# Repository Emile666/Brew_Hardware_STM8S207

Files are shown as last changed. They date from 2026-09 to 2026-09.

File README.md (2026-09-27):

# Brew Automation Hardware with a STM8S207
This PCB is an evolution of what originally was an Arduino with some added hardware. The current PCB features an STM8S207R8, which comes in a 64 pins LQPF package. It has a maximum of 52 GPIO pins, contains 64K Flash, 1536 bytes EEPROM and 6 KB of RAM. Previous PCB versions were made with Eagle, starting with V4.12, KiCad is used.

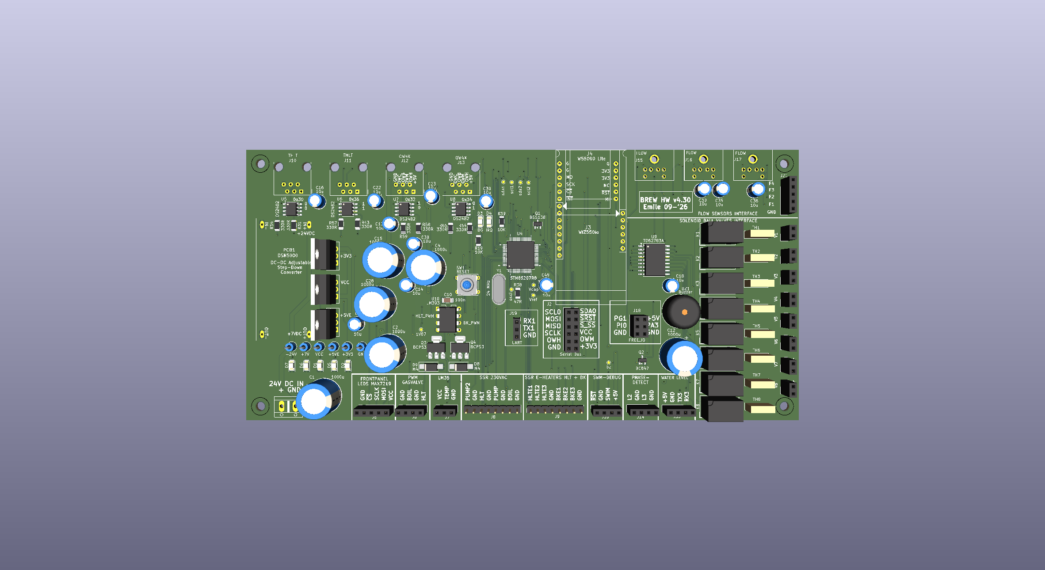
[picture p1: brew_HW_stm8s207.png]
PCB Layout
<br>
*PCB Layout*

# Features
The current PCB and firmware have the following features:
- Reading of **6 x temperature sensors**: two in the HLT (one I2C LM92, one One-Wire DS18B20), one in the MLT (I2C), one in the boil-kettle (One-Wire), one at the output of the counterflow-chiller (One-Wire) and one at the MLT return-manifold (One-Wire).
- Reading of **one hardware temperature** by a LM35 temperature sensor: this is used to protect the Solid State Relays (SSR) from overheating. The LM35 is typically mounted to a heatsink of one of the SSRs that switch a heating-element.
- Reading a maximum of **4 x FS300A flowsensors**: between HLT and MLT, between MLT and boil-kettle, one at the output of the counterflow-chiller and one at the entry of the MLT return-manifold.
- Control of **8 x solenoid ball-valves** at 24 V DC.
- **2 x PWM signals (25 kHz, 28 V DC)** for the modulating gasburners (HLT and boil-kettle burners).
- Control of **4 x SSR outputs at 230 V AC**: the pump, a second pump (for the HLT counterflow-chiller), 230 V enable for the HLT gasburner and 230 V enable for the boil-kettle gasburner.
- Control of **6 x SSR outputs at 230 V AC** for the three phase heating-elements in the HLT and the boil-kettle. With this, heating of the HLT is possible with a gas-burner, with 1, 2 or 3 heating-elements of with any combination of these.
- **Synced SSR outputs** for HLT and boil-kettle, so that you only need **one three-phase connection**. The boil-kettle outputs have priority over the HLT outputs, meaning that if (on any phase of 230 V) both HLT and boil-kettle are heating, only the boil-kettle is activated.
  It is also possible to use just one (or two) of the three-phases, depending on the number of heating-elements inside the HLT and/or boil-kettle. The firmware is capable of addressing one, two or three heating-elements per kettle.
- **Ethernet and USB connection** to PC: USB-connection is used for debugging, main connection between PC-program and the firmware is Ethernet.
- **Frontpanel LEDs (24 in total)** that show the status of all actuators. They are controlled by a MAX7219 LED Display Driver, located on a separate PCB, the frontpanel PCB.

# Schematics (.pdf)
[Brew Hardware schematics](./brew_HW_stm8s207_r430.pdf)<br>
*Brew Hardware Schematics*

# Interactive Bill-of-Materials (BOM)
[Brew Hardware BOM](http://htmlpreview.github.io/?https://github.com/Emile666/Brew_Hardware_STM8S207/blob/main/bom/ibom.html)<br>
*Brew Hardware BOM*

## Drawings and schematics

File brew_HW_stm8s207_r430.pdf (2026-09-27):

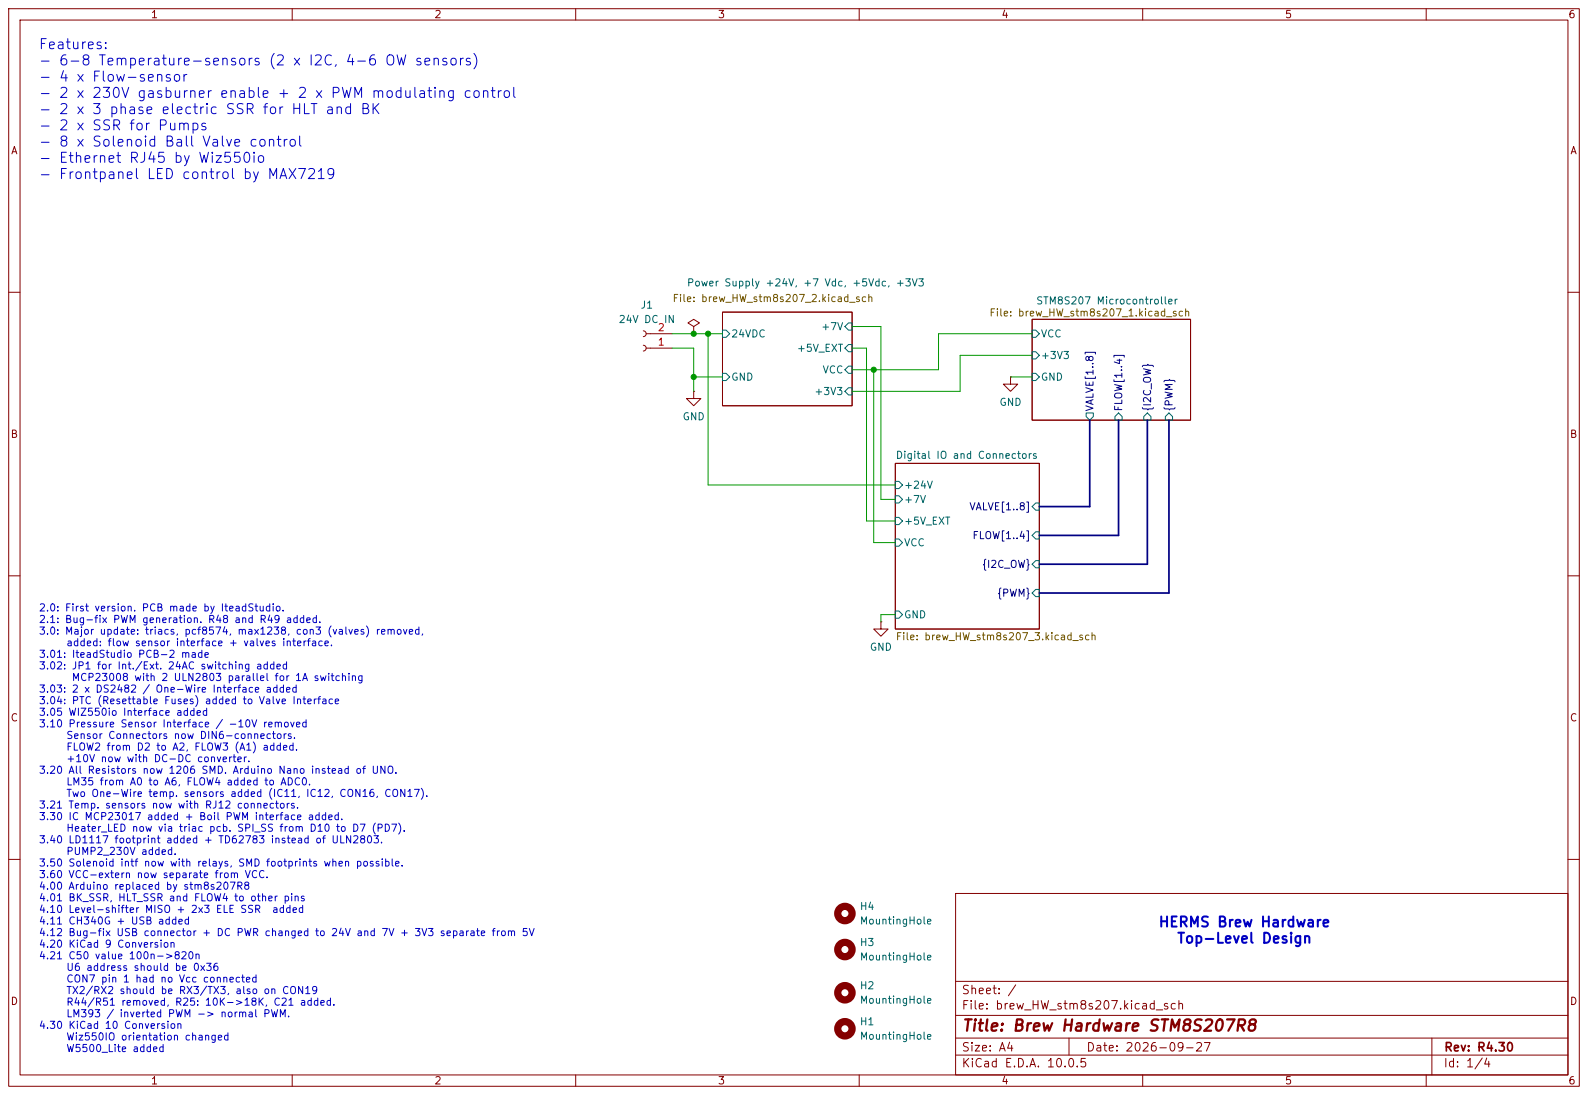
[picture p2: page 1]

Features: - 6-8 Temperature-sensors (2 x I2C, 4-6 OW sensors) - 4 x Flow-sensor - 2 x 230V gasburner enable + 2 x PWM modulating control - 2 x 3 phase electric SSR for HLT and BK - 2 x SSR for Pumps - 8 x Solenoid Ball Valve control - Ethernet RJ45 by Wiz550io - Frontpanel LED control by MAX7219

Digital IO and Connectors File: brew_HW_stm8s207_3.kicad_sch +3V3 GND

2.0: First version. PCB made by IteadStudio. 2.1: Bug-fix PWM generation. R48 and R49 added. 3.0: Major update: triacs, pcf8574, max1238, con3 (valves) removed, added: flow sensor interface + valves interface. 3.01: IteadStudio PCB-2 made 3.02: JP1 for Int./Ext. 24AC switching added MCP23008 with 2 ULN2803 parallel for 1A switching 3.03: 2 x DS2482 / One-Wire Interface added 3.04: PTC (Resettable Fuses) added to Valve Interface 3.05 WIZ550io Interface added 3.10 Pressure Sensor Interface / -10V removed Sensor Connectors now DIN6-connectors. FLOW2 from D2 to A2, FLOW3 (A1) added. +10V now with DC-DC converter. 3.20 All Resistors now 1206 SMD. Arduino Nano instead of UNO. LM35 from A0 to A6, FLOW4 added to ADC0. Two One-Wire temp. sensors added (IC11, IC12, CON16, CON17). 3.21 Temp. sensors now with RJ12 connectors. 3.30 IC MCP23017 added + Boil PWM interface added. Heater_LED now via triac pcb. SPI_SS from D10 to D7 (PD7). 3.40 LD1117 footprint added + TD62783 instead of ULN2803. PUMP2_230V added. 3.50 Solenoid intf now with relays, SMD footprints when possible. 3.60 VCC-extern now separate from VCC. 4.00 Arduino replaced by stm8s207R8

4.01 BK_SSR, HLT_SSR and FLOW4 to other pins 4.10 Level-shifter MISO + 2x3 ELE SSR added 4.11 CH340G + USB added 4.12 Bug-fix USB connector + DC PWR changed to 24V and 7V + 3V3 separate from 5V 4.20 KiCad 9 Conversion 4.21 C50 value 100n->820n U6 address should be 0x36 CON7 pin 1 had no Vcc connected

TX2/RX2 should be RX3/TX3, also on CON19 R44/R51 removed, R25: 10K->18K, C21 added. LM393 / inverted PWM -> normal PWM. 4.30 KiCad 10 Conversion Wiz550IO orientation changed W5500_Lite added

Size: A4 | Rev: R4.30
KiCad E.D.A. 10.0.5 | Id: 1/4

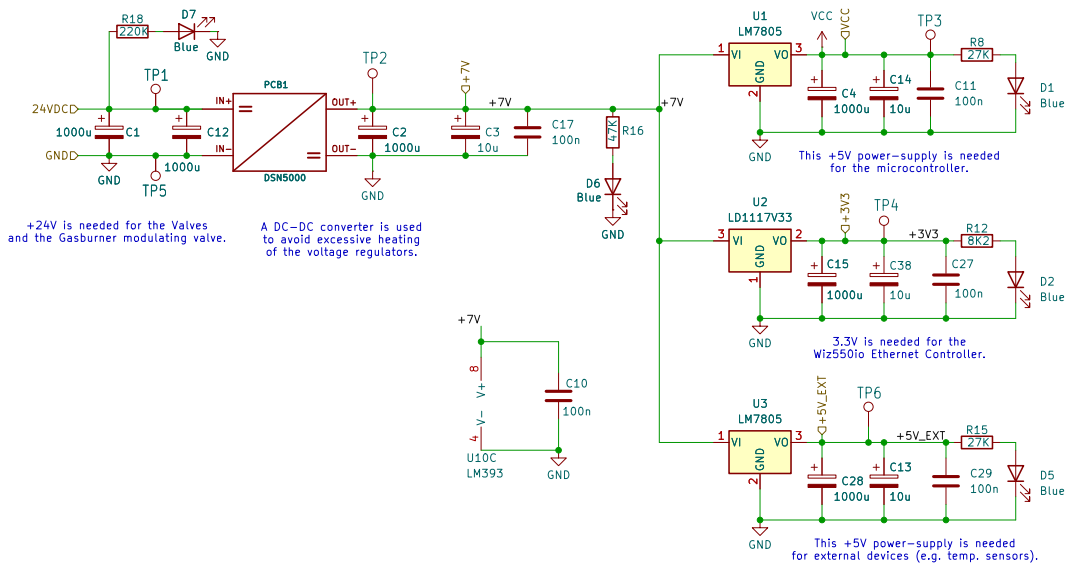
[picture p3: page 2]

for the microcontroller. A DC-DC converter is used

for external devices (e.g. temp. sensors). This +5V power-supply is needed

to avoid excessive heating
of the voltage regulators.

Sheet: /Power Supply +24V, +7 Vdc, +5Vdc, +3V3/
File: brew_HW_stm8s207_2.kicad_sch
Title: Brew Hardware STM8S207R8

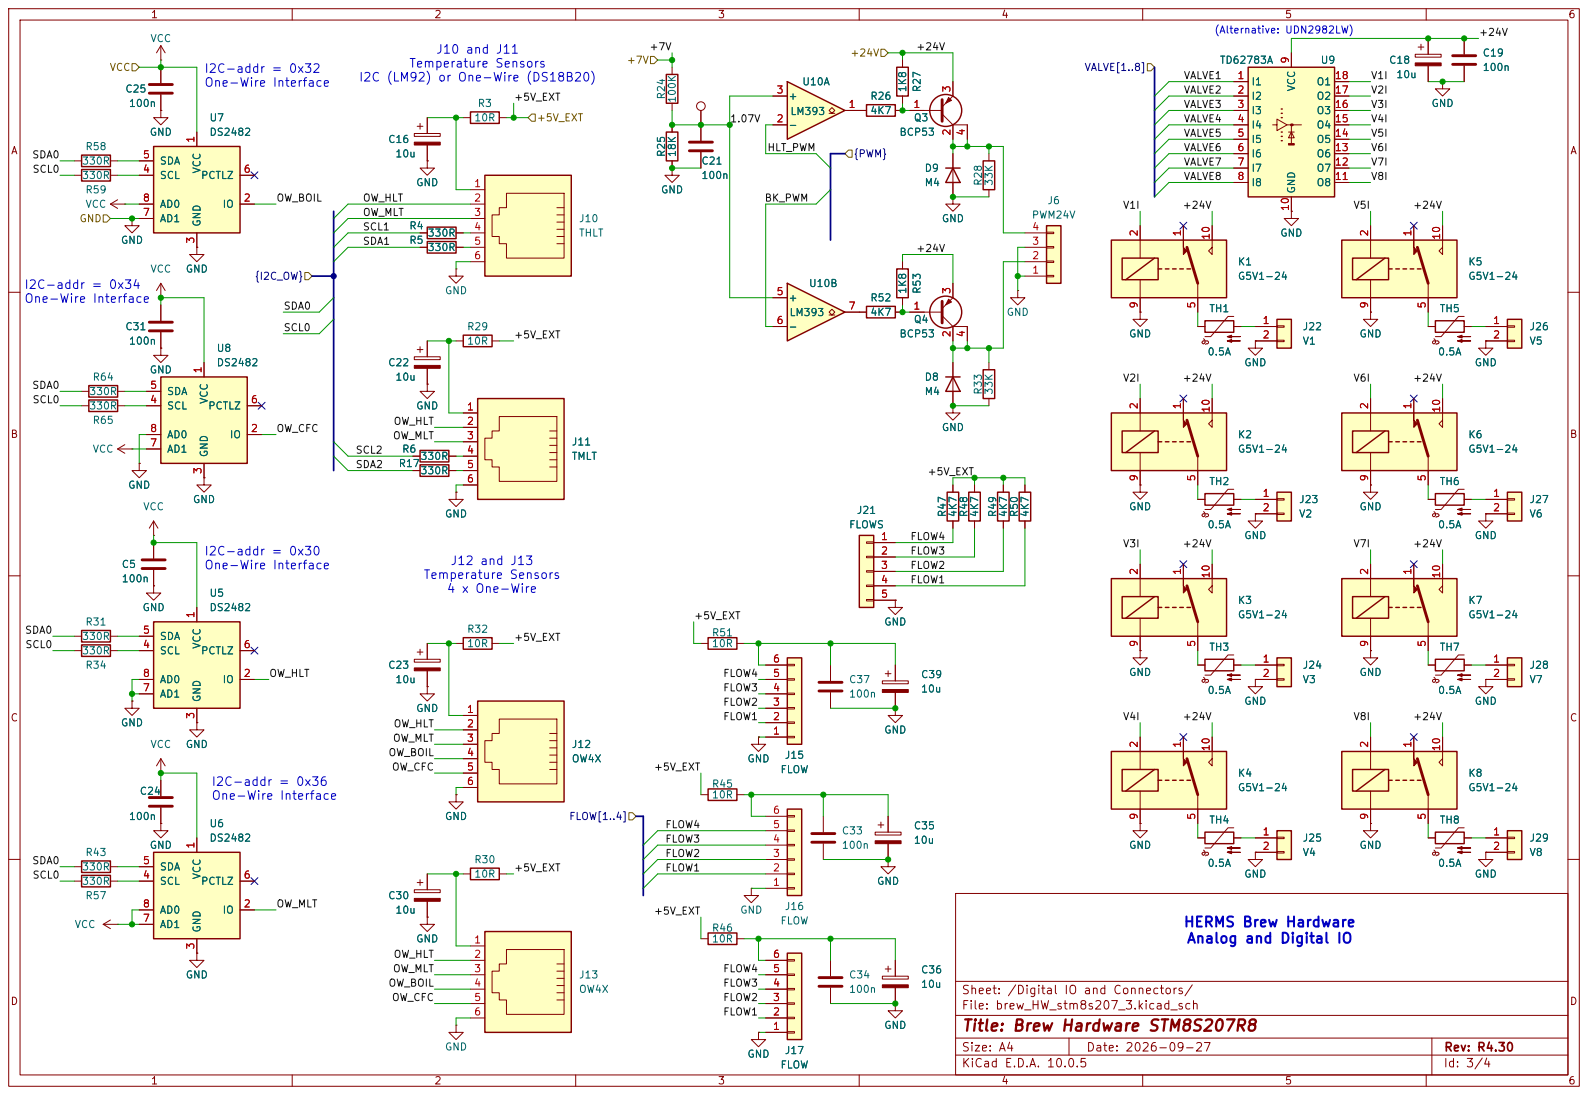
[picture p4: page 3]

330R | SCL 4

HERMS Brew Hardware
Analog and Digital IO

Sheet: /Digital IO and Connectors/
File: brew_HW_stm8s207_3.kicad_sch
Title: Brew Hardware STM8S207R8

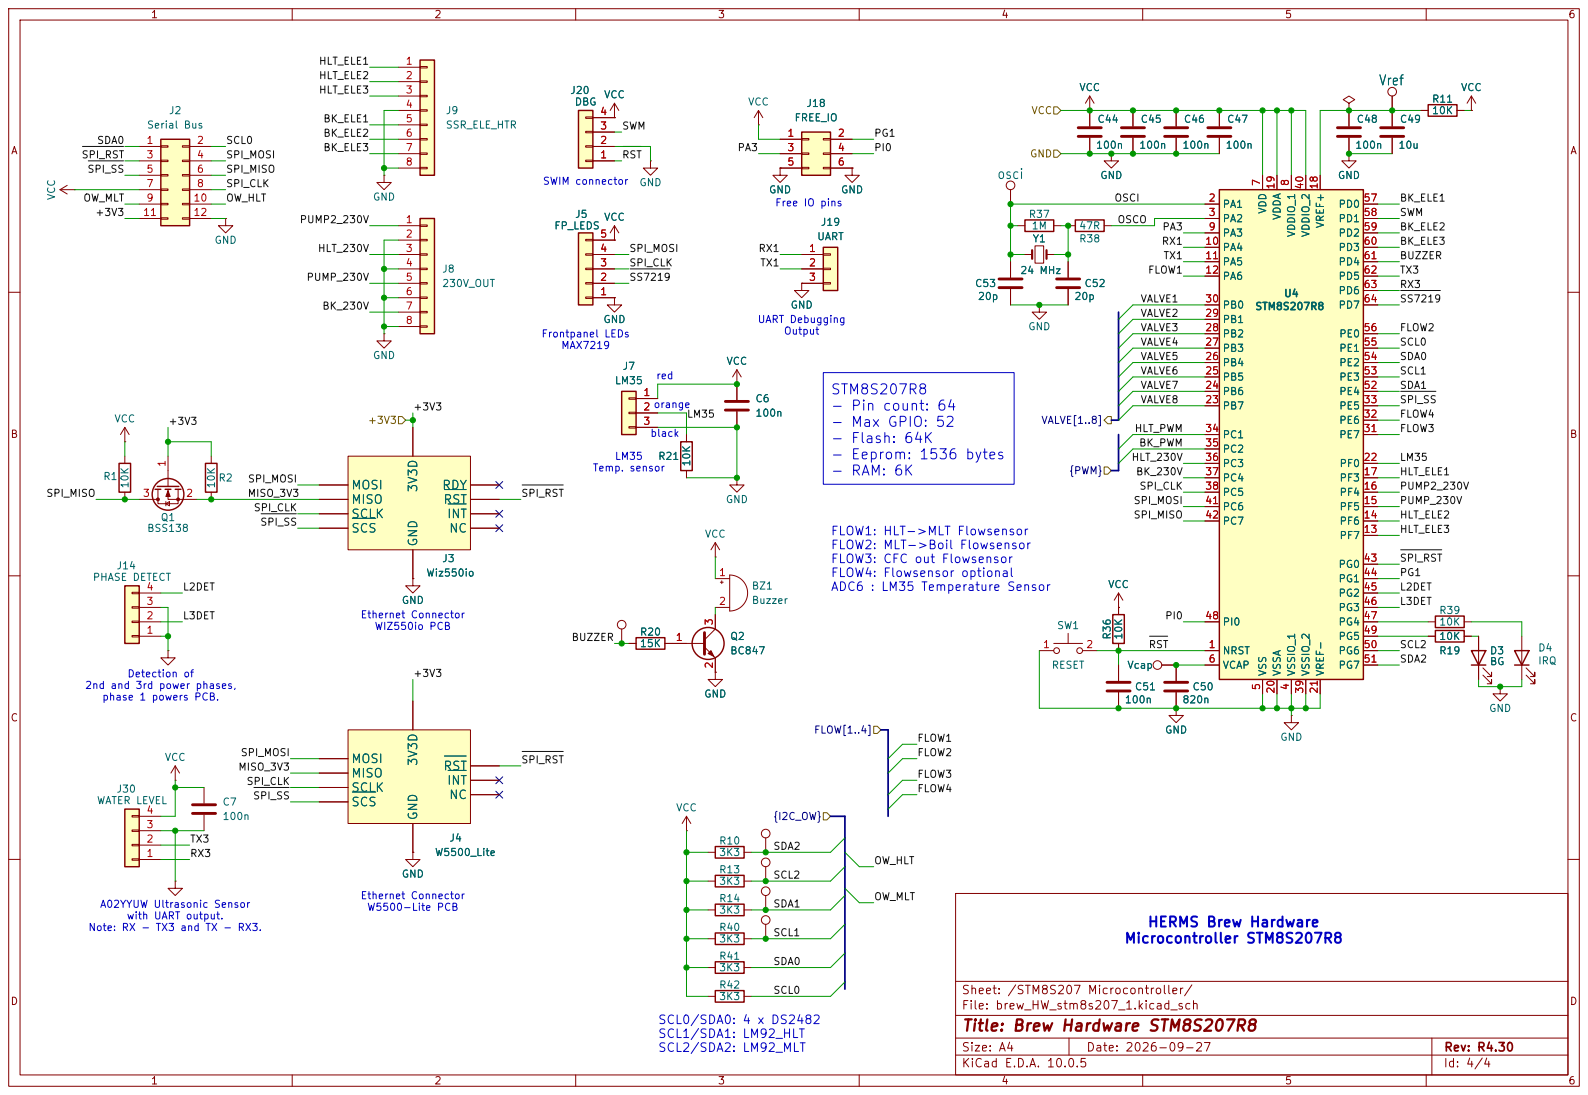
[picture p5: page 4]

8 PA3 9 PA4 10 PA5 11 PA6 12 PF7 13 PF6 14 PF5 15 PF4 16 PF3 17 VREF+ 18 VDDA 19 VSSA 20 VREF- 21 PF0 22 PB7 23 PB6 24 PB5 25 PB4 26 PB3 27 PB2 28 PB1 29 PB0 30 PE7 31 PE6 32 PE5 33 PC1 34 PC2 35 PC3 36 PC4 37 PC5 38 VSSIO_2 39 VDDIO_2 40 PC6 41 PC7 42 PG0 43 PG1 44 PG2 45 PG3 46 PG4 47 PI0 48 PG5 49 PG6 50 PG7 51 PE4 52 PE3 53 PE2 54 PE1 55 PE0 56 PD0 57 PD1 58 PD2 59 PD3 60 PD4 61 PD5 62 PD6 63 PD7 64 U4

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

Output Detection of 2nd and 3rd power phases,

STM8S207R8 - Pin count: 64 - Max GPIO: 52 - Flash: 64K - Eeprom: 1536 bytes - RAM: 6K

orange black Ethernet Connector WIZ550io PCB

phase 1 powers PCB. A02YYUW Ultrasonic Sensor with UART output. Note: RX - TX3 and TX - RX3.

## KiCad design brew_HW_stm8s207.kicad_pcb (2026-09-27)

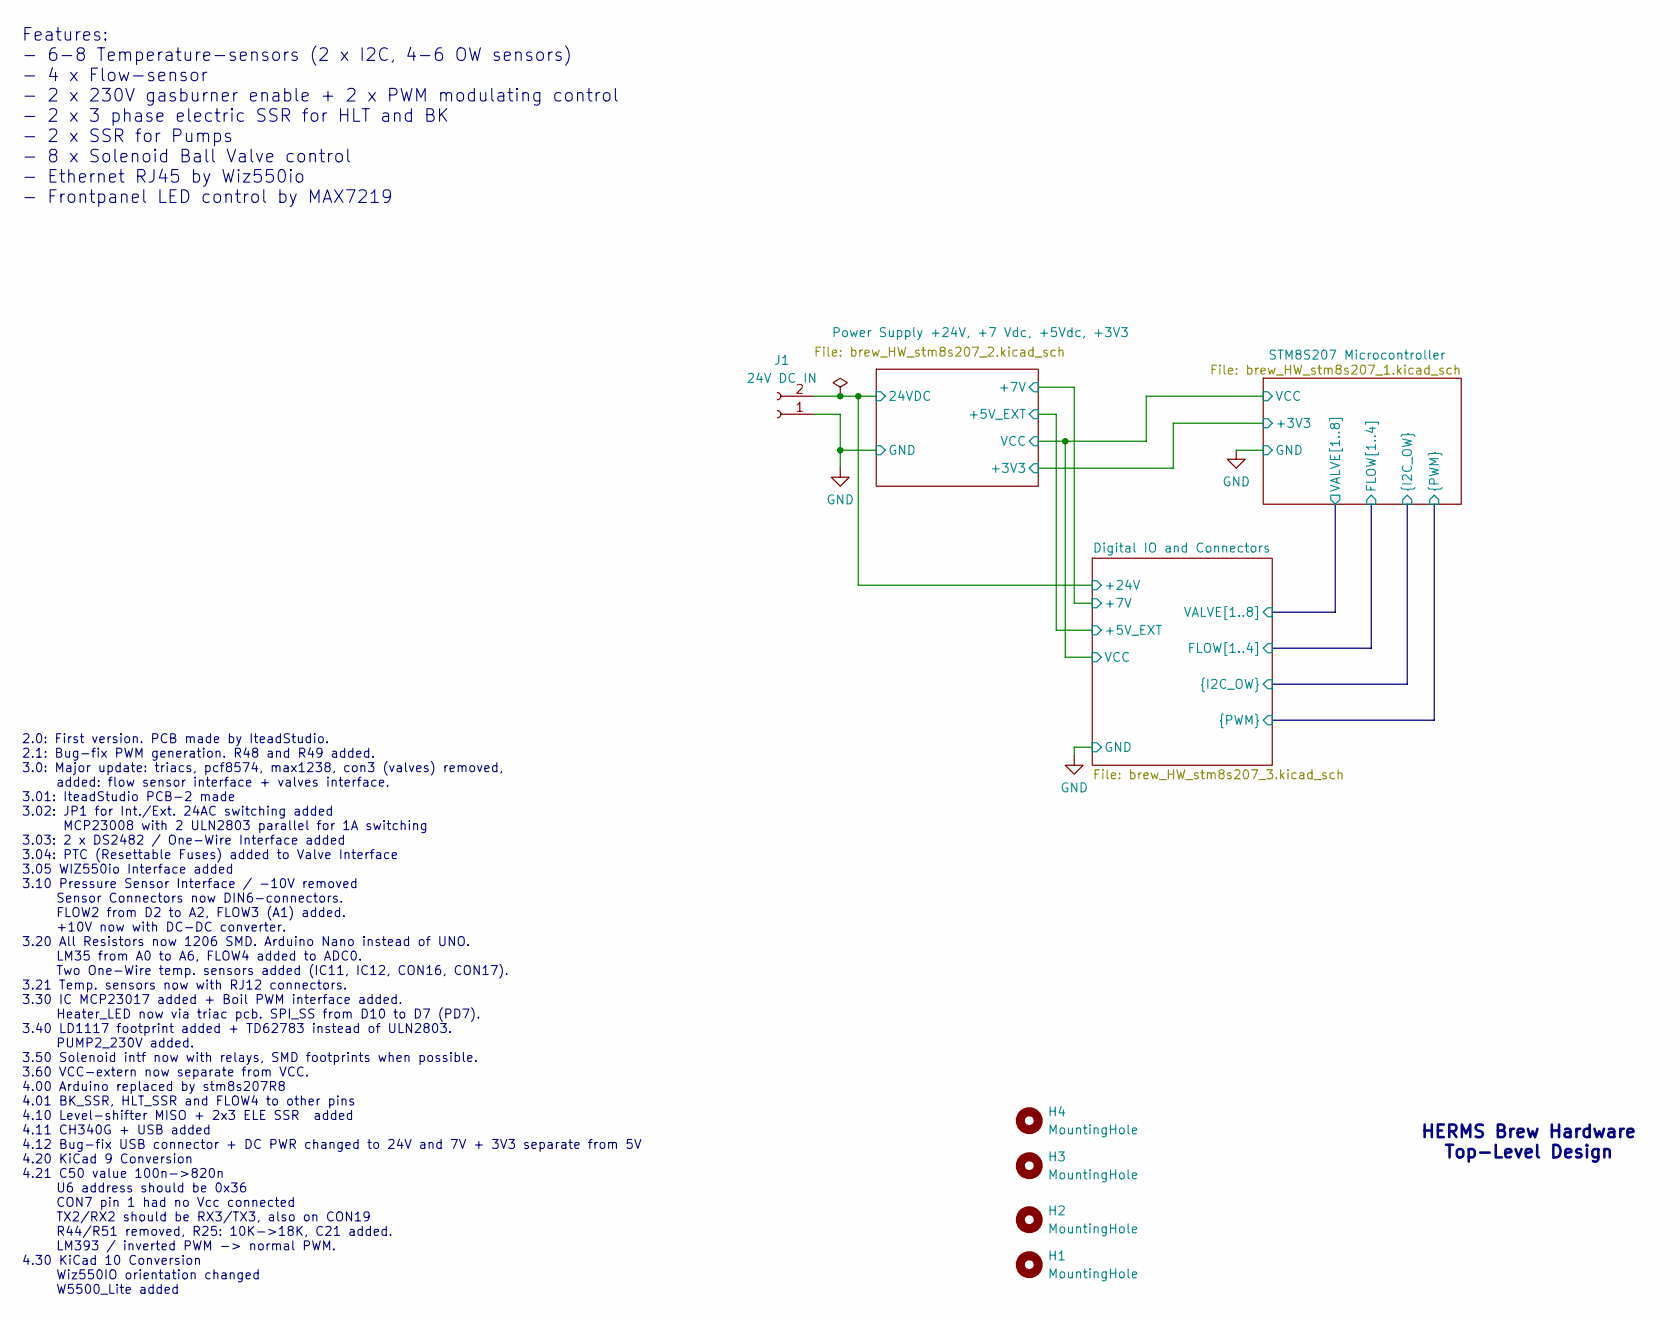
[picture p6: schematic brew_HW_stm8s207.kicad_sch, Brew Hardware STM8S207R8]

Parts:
H1, H2, H3, H4: MountingHole; MountingHole_3.2mm_M3
J1: 24V DC IN; AK500_2

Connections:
/Digital IO and Connectors/+24V: J1.2; also elsewhere on the board
GND: J1.1; also elsewhere on the board

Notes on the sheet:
Features: - 6-8 Temperature-sensors (2 x I2C, 4-6 OW sensors) - 4 x Flow-sensor - 2 x 230V gasburner enable + 2 x PWM modulating control - 2 x 3 phase electric SSR for HLT and BK - 2 x SSR for Pumps - 8 x Solenoid Ball Valve control - Ethernet RJ45 by Wiz550io - Frontpanel LED control by MAX7219
2.0: First version. PCB made by IteadStudio. 2.1: Bug-fix PWM generation. R48 and R49 added. 3.0: Major update: triacs, pcf8574, max1238, con3 (valves) removed, added: flow sensor interface + valves interface. 3.01: IteadStudio PCB-2 made 3.02: JP1 for Int./Ext. 24AC switching added MCP23008 with 2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
HERMS Brew Hardware Top-Level Design

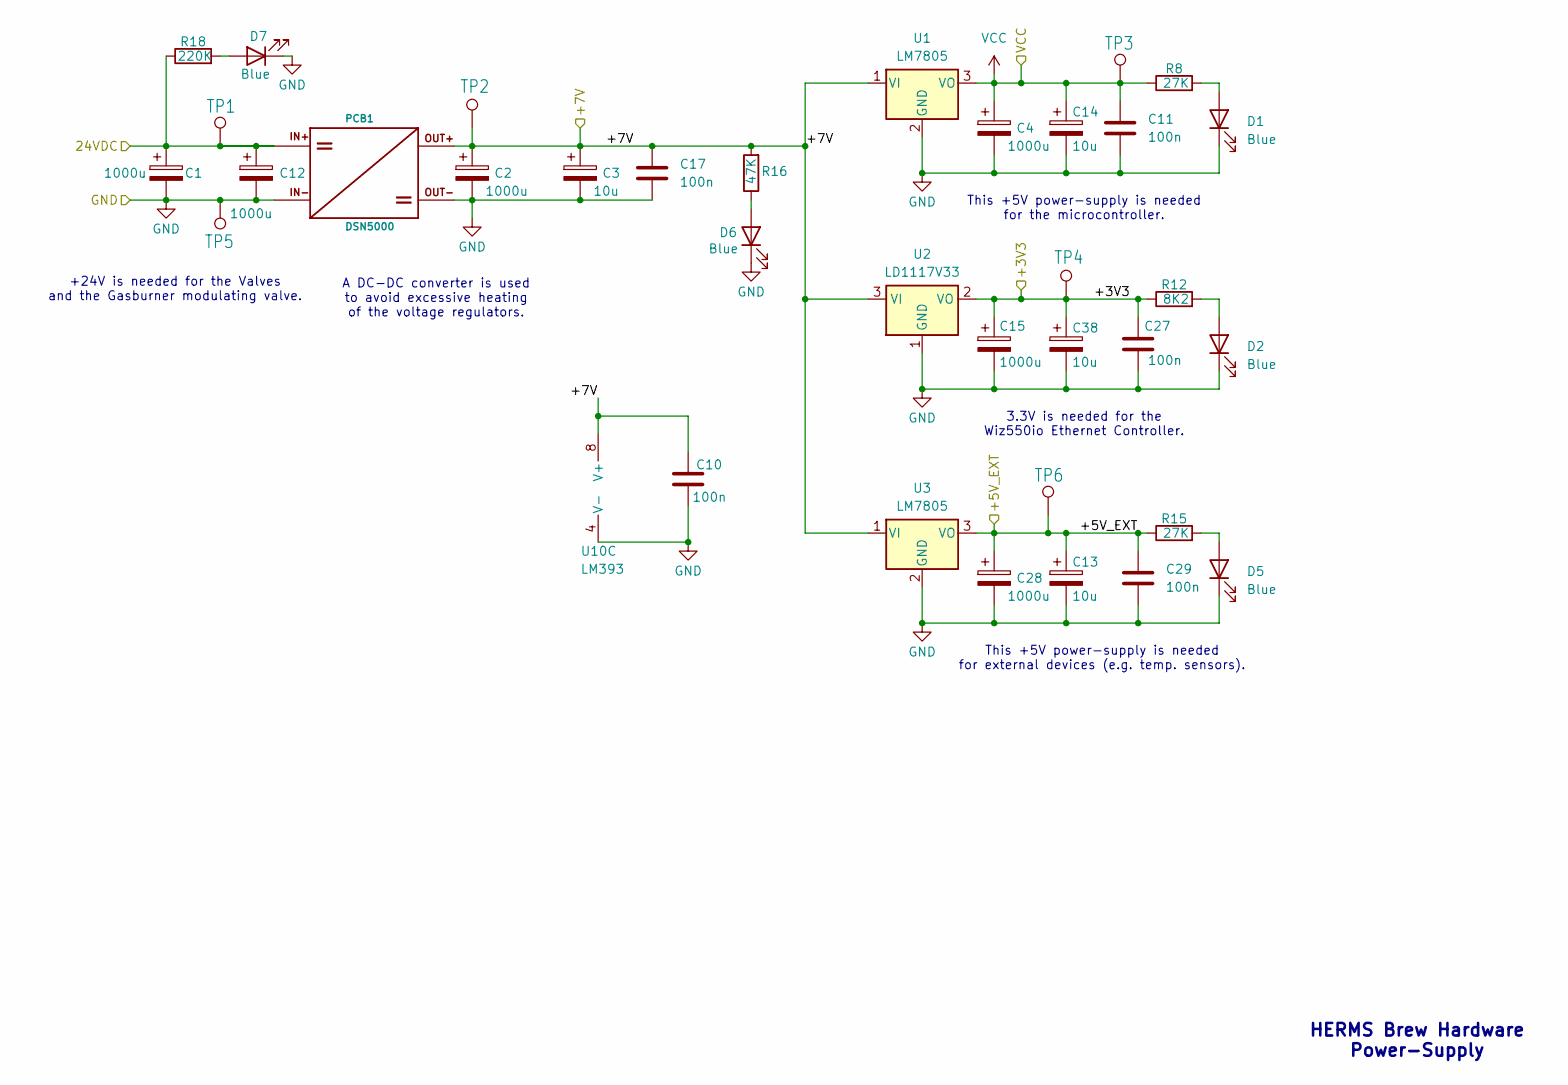
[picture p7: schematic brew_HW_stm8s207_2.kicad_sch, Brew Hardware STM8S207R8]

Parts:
C1, C2, C4, C12, C15, C28: 1000u; CP_Radial_D12.5mm_P5.00mm
C3, C13, C14, C38: 10u; CP_Radial_D5.0mm_P2.00mm
C10, C11, C17, C27, C29: 100n; C_1206_3216Metric
D1, D2, D5, D6, D7: Blue; LED_1206_3216Metric
PCB1: DSN5000; DSN5000_DCDC_CONVERTER
R8, R15: 27K; R_1206_3216Metric
R12: 8K2; R_1206_3216Metric
R16: 47K; R_1206_3216Metric
R18: 220K; R_1206_3216Metric
TP1: +24V; TestPoint_Loop_D2.54mm_Drill1.5mm_Beaded
TP2: +7V; TestPoint_Loop_D2.54mm_Drill1.5mm_Beaded
TP3: VCC; TestPoint_Loop_D2.54mm_Drill1.5mm_Beaded
TP4: +3V3; TestPoint_Loop_D2.54mm_Drill1.5mm_Beaded
TP5: GND; TestPoint_Loop_D2.54mm_Drill1.5mm_Beaded
TP6: +5VE; TestPoint_Loop_D2.54mm_Drill1.5mm_Beaded
U1, U3: LM7805; TO-220-3_Vertical
U2: LD1117V33; TO-220-3_Vertical
U10: LM393; DIP-8_W7.62mm

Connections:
/Digital IO and Connectors/+5V_EXT: C13.1, C28.1, C29.1, R15.1, TP6.1 (1_1), U3.3 (VO); also elsewhere on the board
/Digital IO and Connectors/+7V: C2.1, C3.1, C10.1, C17.1, PCB1.P$3, R16.2, TP2.1 (1_1), U1.1 (VI), U2.3 (VI), U3.1 (VI), U10.8 (V+); also elsewhere on the board
/Digital IO and Connectors/+24V: C1.1, C12.1, PCB1.PX$1 (IN+), R18.1, TP1.1 (1_1); also elsewhere on the board
/Power Supply +24V, +7 Vdc, +5Vdc, +3V3/+3V3: C15.1, C27.1, C38.1, R12.1, TP4.1 (1_1), U2.2 (VO); also elsewhere on the board
GND: C1.2, C2.2, C3.2, C4.2, C10.2, C11.2, C12.2, C13.2, C14.2, C15.2, C17.2, C27.2, C28.2, C29.2, C38.2, D1.1 (K), D2.1 (K), D5.1 (K), D6.1 (K), D7.1 (K), PCB1.P$2, PCB1.P$4, TP5.1 (1_1), U1.2 (GND), U2.1 (GND), U3.2 (GND), U10.4 (V-); also elsewhere on the board
unnamed: D1.2 (A), R8.2
unnamed: D2.2 (A), R12.2
unnamed: D5.2 (A), R15.2
unnamed: D6.2 (A), R16.1
unnamed: D7.2 (A), R18.2
VCC: C4.1, C11.1, C14.1, R8.1, TP3.1 (1_1), U1.3 (VO); also elsewhere on the board

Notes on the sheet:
This +5V power-supply is needed for external devices (e.g. temp. sensors).
+24V is needed for the Valves and the Gasburner modulating valve.
HERMS Brew Hardware Power-Supply
This +5V power-supply is needed for the microcontroller.
A DC-DC converter is used to avoid excessive heating of the voltage regulators.
3.3V is needed for the Wiz550io Ethernet Controller.

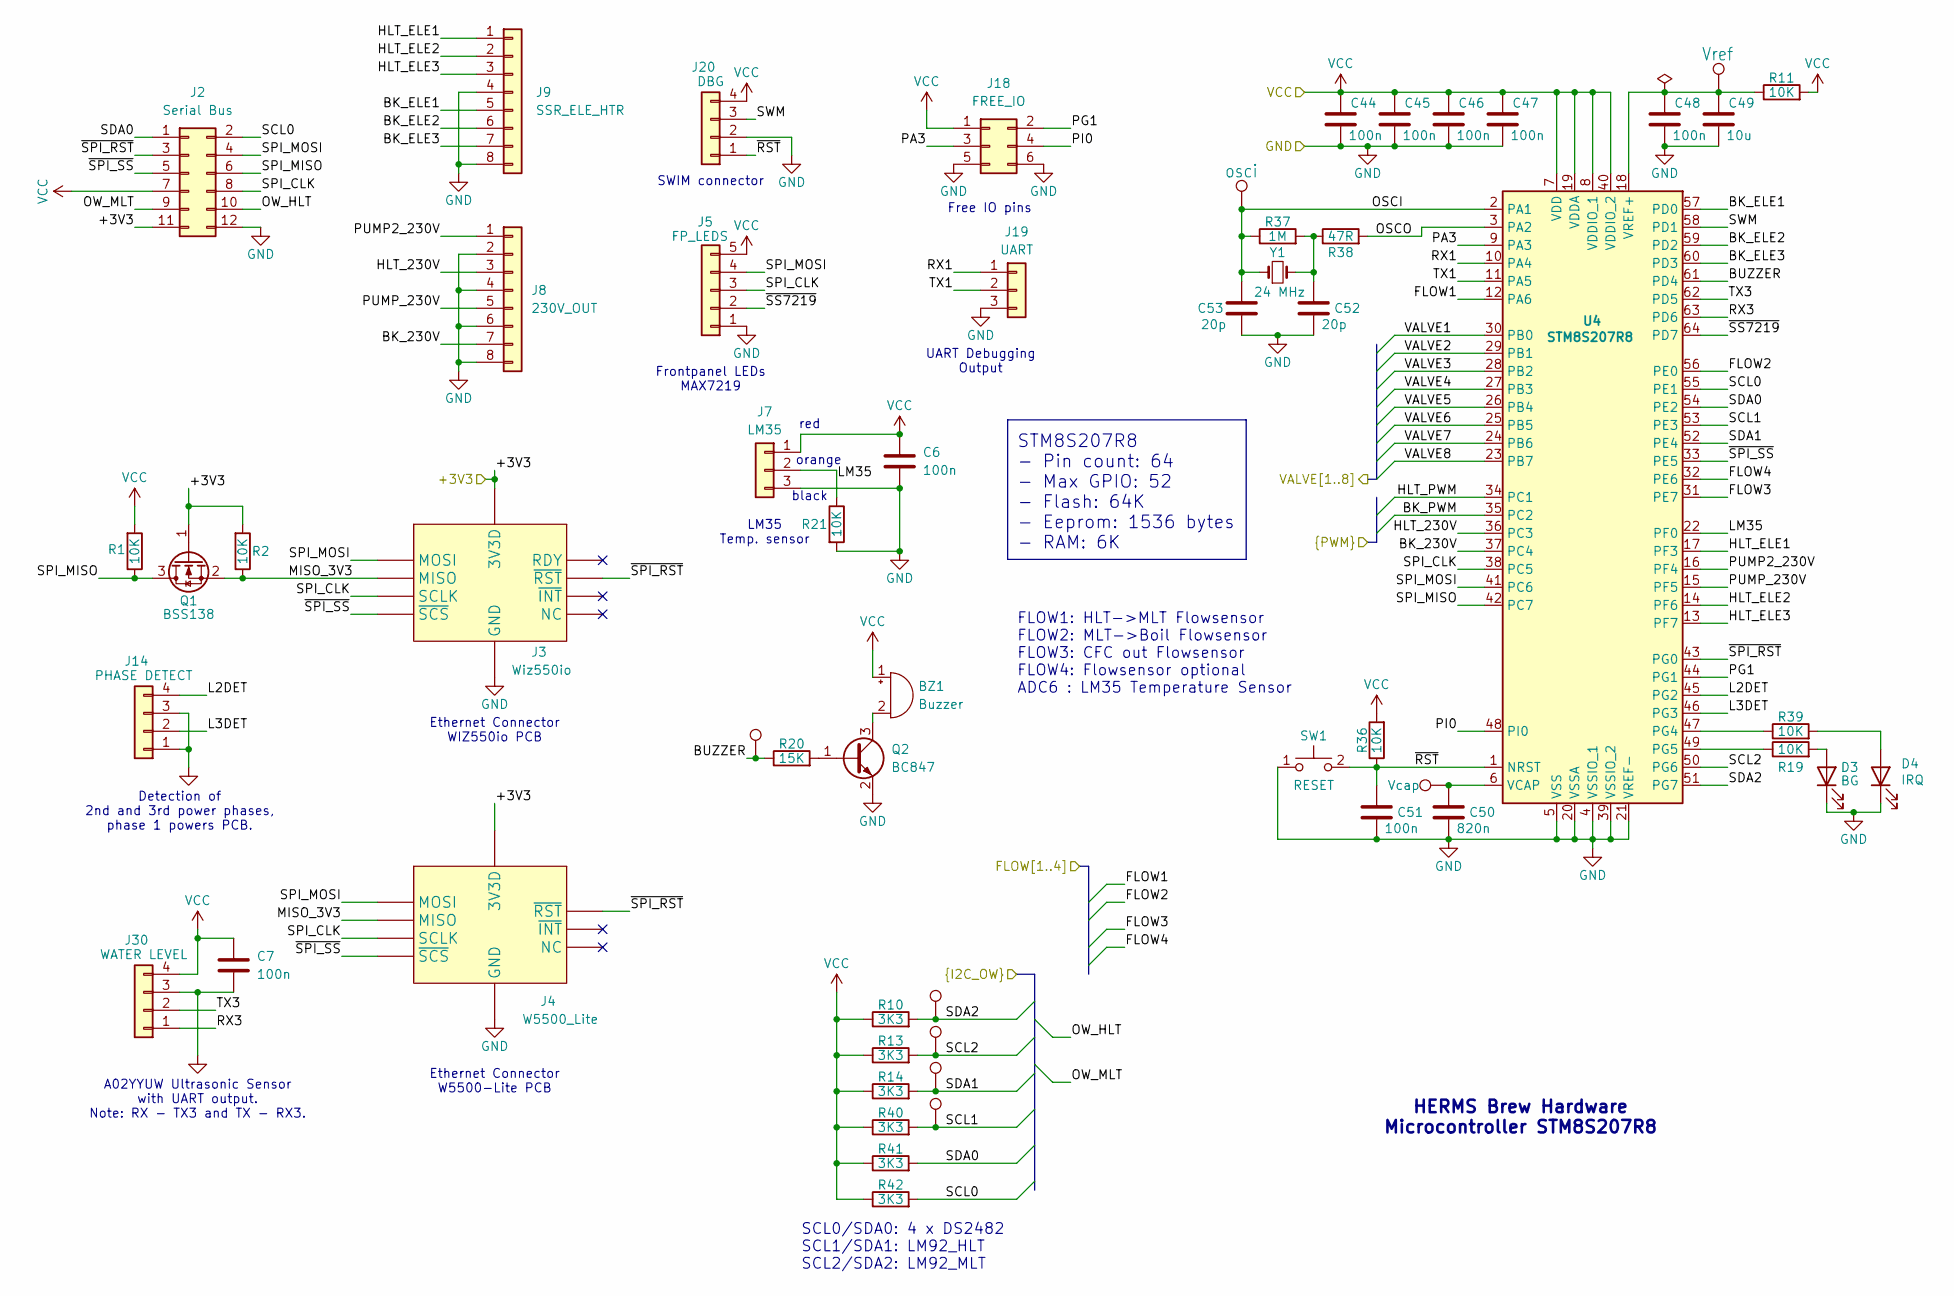
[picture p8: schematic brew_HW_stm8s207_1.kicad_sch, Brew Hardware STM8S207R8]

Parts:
BZ1: Buzzer; Buzzer_12x9.5RM7.6
C6, C7, C44, C45, C46, C47, C48, C51: 100n; C_1206_3216Metric
C49: 10u; CP_Radial_D5.0mm_P2.00mm
C50: 820n; C_1206_3216Metric
C52, C53: 20p; C_1206_3216Metric
D3: BG; LED_1206_3216Metric
D4: IRQ; LED_1206_3216Metric
J2: Serial Bus; PinSocket_2x06_P2.54mm_Vertical
J3: Wiz550io; WIZ550IO
J4: W5500_Lite; W55000_Lite
J5: FP_LEDS; PinSocket_1x05_P2.54mm_Vertical
J7: LM35; PinSocket_1x03_P2.54mm_Vertical
J8: 230V_OUT; PinHeader_1x08_P2.54mm_Vertical
J9: SSR_ELE_HTR; PinHeader_1x08_P2.54mm_Vertical
J14: PHASE DETECT; PinSocket_1x04_P2.54mm_Vertical
J18: FREE_IO; PinSocket_2x03_P2.54mm_Vertical
J19: UART; PinSocket_1x03_P2.54mm_Vertical
J20: DBG; PinSocket_1x04_P2.54mm_Vertical
J30: WATER LEVEL; PinSocket_1x04_P2.54mm_Vertical
Q1: BSS138; SOT-23
Q2: BC847; SOT-23
R1, R2, R11, R19, R21, R36, R39: 10K; R_1206_3216Metric
R10, R13, R14, R40, R41, R42: 3K3; R_1206_3216Metric
R20: 15K; R_1206_3216Metric
R37: 1M; R_1206_3216Metric
R38: 47R; R_1206_3216Metric
SW1: RESET; SW_Tactile_Straight_KSA0Axx1LFTR
TP7: Vref; TestPoint_Pad_D1.0mm
TP8: Vcap; TestPoint_Pad_D1.0mm
TP9: sda2; TestPoint_Pad_D1.0mm
TP10: scl2; TestPoint_Pad_D1.0mm
TP11: sda1; TestPoint_Pad_D1.0mm
TP12: scl1; TestPoint_Pad_D1.0mm
TP13: bz; TestPoint_Pad_D1.0mm
TP14: osci; TestPoint_Pad_D1.0mm
U4: STM8S207R8; LQFP-64_10x10mm_P0.5mm
Y1: 24 MHz; Crystal_HC49-4H_Vertical

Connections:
/Digital IO and Connectors/BK_PWM: U4.35 (PC2); also elsewhere on the board
/Digital IO and Connectors/FLOW1: U4.12 (PA6); also elsewhere on the board
/Digital IO and Connectors/FLOW2: U4.56 (PE0); also elsewhere on the board
/Digital IO and Connectors/FLOW3: U4.31 (PE7); also elsewhere on the board
/Digital IO and Connectors/FLOW4: U4.32 (PE6); also elsewhere on the board
/Digital IO and Connectors/HLT_PWM: U4.34 (PC1); also elsewhere on the board
/Digital IO and Connectors/OW_HLT: J2.10; also elsewhere on the board
/Digital IO and Connectors/OW_MLT: J2.9; also elsewhere on the board
/Digital IO and Connectors/SCL0: J2.2, R42.2, U4.55 (PE1); also elsewhere on the board
/Digital IO and Connectors/SCL1: R40.2, TP12.1 (1_1), U4.53 (PE3); also elsewhere on the board
/Digital IO and Connectors/SCL2: R13.2, TP10.1 (1_1), U4.50 (PG6); also elsewhere on the board
/Digital IO and Connectors/SDA0: J2.1, R41.2, U4.54 (PE2); also elsewhere on the board
/Digital IO and Connectors/SDA1: R14.2, TP11.1 (1_1), U4.52 (PE4); also elsewhere on the board
/Digital IO and Connectors/SDA2: R10.2, TP9.1 (1_1), U4.51 (PG7); also elsewhere on the board
/Digital IO and Connectors/VALVE1: U4.30 (PB0); also elsewhere on the board
/Digital IO and Connectors/VALVE2: U4.29 (PB1); also elsewhere on the board
/Digital IO and Connectors/VALVE3: U4.28 (PB2); also elsewhere on the board
/Digital IO and Connectors/VALVE4: U4.27 (PB3); also elsewhere on the board
/Digital IO and Connectors/VALVE5: U4.26 (PB4); also elsewhere on the board
/Digital IO and Connectors/VALVE6: U4.25 (PB5); also elsewhere on the board
/Digital IO and Connectors/VALVE7: U4.24 (PB6); also elsewhere on the board
/Digital IO and Connectors/VALVE8: U4.23 (PB7); also elsewhere on the board
/Power Supply +24V, +7 Vdc, +5Vdc, +3V3/+3V3: J2.11, J3.6 (3V3D), J4.6 (3V3D), Q1.1 (G), R2.2; also elsewhere on the board
/STM8S207 Microcontroller/BK_230V: J8.7, U4.37 (PC4)
/STM8S207 Microcontroller/BK_ELE1: J9.5, U4.57 (PD0)
/STM8S207 Microcontroller/BK_ELE2: J9.6, U4.59 (PD2)
/STM8S207 Microcontroller/BK_ELE3: J9.7, U4.60 (PD3)
/STM8S207 Microcontroller/BUZZER: R20.1, TP13.1 (1_1), U4.61 (PD4)
/STM8S207 Microcontroller/HLT_230V: J8.3, U4.36 (PC3)
/STM8S207 Microcontroller/HLT_ELE1: J9.1, U4.17 (PF3)
/STM8S207 Microcontroller/HLT_ELE2: J9.2, U4.14 (PF6)
/STM8S207 Microcontroller/HLT_ELE3: J9.3, U4.13 (PF7)
/STM8S207 Microcontroller/L2DET: J14.4, U4.45 (PG2)
/STM8S207 Microcontroller/L3DET: J14.2, U4.46 (PG3)
/STM8S207 Microcontroller/LM35: J7.2, R21.1, U4.22 (PF0)
/STM8S207 Microcontroller/MISO_3V3: J3.3 (MISO), J4.3 (MISO), Q1.2 (S), R2.1
/STM8S207 Microcontroller/OSCI: C53.1, R37.1, TP14.1 (1_1), U4.2 (PA1), Y1.1
/STM8S207 Microcontroller/OSCO: R38.2, U4.3 (PA2)
/STM8S207 Microcontroller/PA3: J18.3, U4.9 (PA3)
/STM8S207 Microcontroller/PG1: J18.2, U4.44 (PG1)
/STM8S207 Microcontroller/PI0: J18.4, U4.48 (PI0)
/STM8S207 Microcontroller/PUMP2_230V: J8.1, U4.16 (PF4)
/STM8S207 Microcontroller/PUMP_230V: J8.5, U4.15 (PF5)
/STM8S207 Microcontroller/RX1: J19.1, U4.10 (PA4)
/STM8S207 Microcontroller/RX3: J30.1, U4.63 (PD6)
/STM8S207 Microcontroller/SPI_CLK: J2.8, J3.4 (SCLK), J4.4 (SCLK), J5.3, U4.38 (PC5)
/STM8S207 Microcontroller/SPI_MISO: J2.6, Q1.3 (D), R1.1, U4.42 (PC7)
/STM8S207 Microcontroller/SPI_MOSI: J2.4, J3.2 (MOSI), J4.2 (MOSI), J5.4, U4.41 (PC6)
/STM8S207 Microcontroller/SWM: J20.3, U4.58 (PD1)
/STM8S207 Microcontroller/TX1: J19.2, U4.11 (PA5)
/STM8S207 Microcontroller/TX3: J30.2, U4.62 (PD5)
/STM8S207 Microcontroller/~RST: C51.1, J20.1, R36.1, SW1.2, U4.1 (NRST)
/STM8S207 Microcontroller/~SPI_RST: J2.3, J3.9 (~RST), J4.9 (~RST), U4.43 (PG0)
/STM8S207 Microcontroller/~SPI_SS: J2.5, J3.5 (~SCS), J4.5 (~SCS), U4.33 (PE5)
/STM8S207 Microcontroller/~SS7219: J5.2, U4.64 (PD7)
GND: C6.2, C7.2, C44.2, C45.2, C46.2, C47.2, C48.2, C49.2, C50.2, C51.2, C52.2, C53.2, D3.1 (K), D4.1 (K), J2.12, J3.1 (GND), J4.1 (GND), J5.1, J7.3, J8.2, J8.4, J8.6, J8.8, J9.4, J9.8, J14.1, J14.3, J18.5, J18.6, J19.3, J20.2, J30.3, Q2.2 (E), R21.2, SW1.1, U4.4 (VSSIO_1), U4.5 (VSS), U4.20 (VSSA), U4.21 (VREF-), U4.39 (VSSIO_2); also elsewhere on the board
unnamed: BZ1.2 (-), Q2.3 (C)
unnamed: C52.1, R37.2, R38.1, Y1.2
unnamed: D3.2 (A), R19.2
unnamed: D4.2 (A), R39.2
unnamed: Q2.1 (B), R20.2
unnamed: R39.1, U4.47 (PG4)
unnamed: R19.1, U4.49 (PG5)
unnamed: C50.1, TP8.1 (1_1), U4.6 (VCAP)
unnamed: C48.1, C49.1, R11.1, TP7.1 (1_1), U4.18 (VREF+)
VCC: BZ1.1 (+), C6.1, C7.1, C44.1, C45.1, C46.1, C47.1, J2.7, J5.5, J7.1, J18.1, J20.4, J30.4, R1.2, R10.1, R11.2, R13.1, R14.1, R36.2, R40.1, R41.1, R42.1, U4.7 (VDD), U4.8 (VDDIO_1), U4.19 (VDDA), U4.40 (VDDIO_2); also elsewhere on the board

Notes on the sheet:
SWIM connector
Ethernet Connector WIZ550io PCB
SCL0/SDA0: 4 x DS2482 SCL1/SDA1: LM92_HLT SCL2/SDA2: LM92_MLT
black
FLOW1: HLT->MLT Flowsensor FLOW2: MLT->Boil Flowsensor FLOW3: CFC out Flowsensor FLOW4: Flowsensor optional ADC6 : LM35 Temperature Sensor
LM35 Temp. sensor
Frontpanel LEDs MAX7219
Ethernet Connector W5500-Lite PCB
orange
HERMS Brew Hardware Microcontroller STM8S207R8
STM8S207R8 - Pin count: 64 - Max GPIO: 52 - Flash: 64K - Eeprom: 1536 bytes - RAM: 6K
UART Debugging Output
A02YYUW Ultrasonic Sensor with UART output. Note: RX - TX3 and TX - RX3.
Detection of 2nd and 3rd power phases, phase 1 powers PCB.
Free IO pins
red

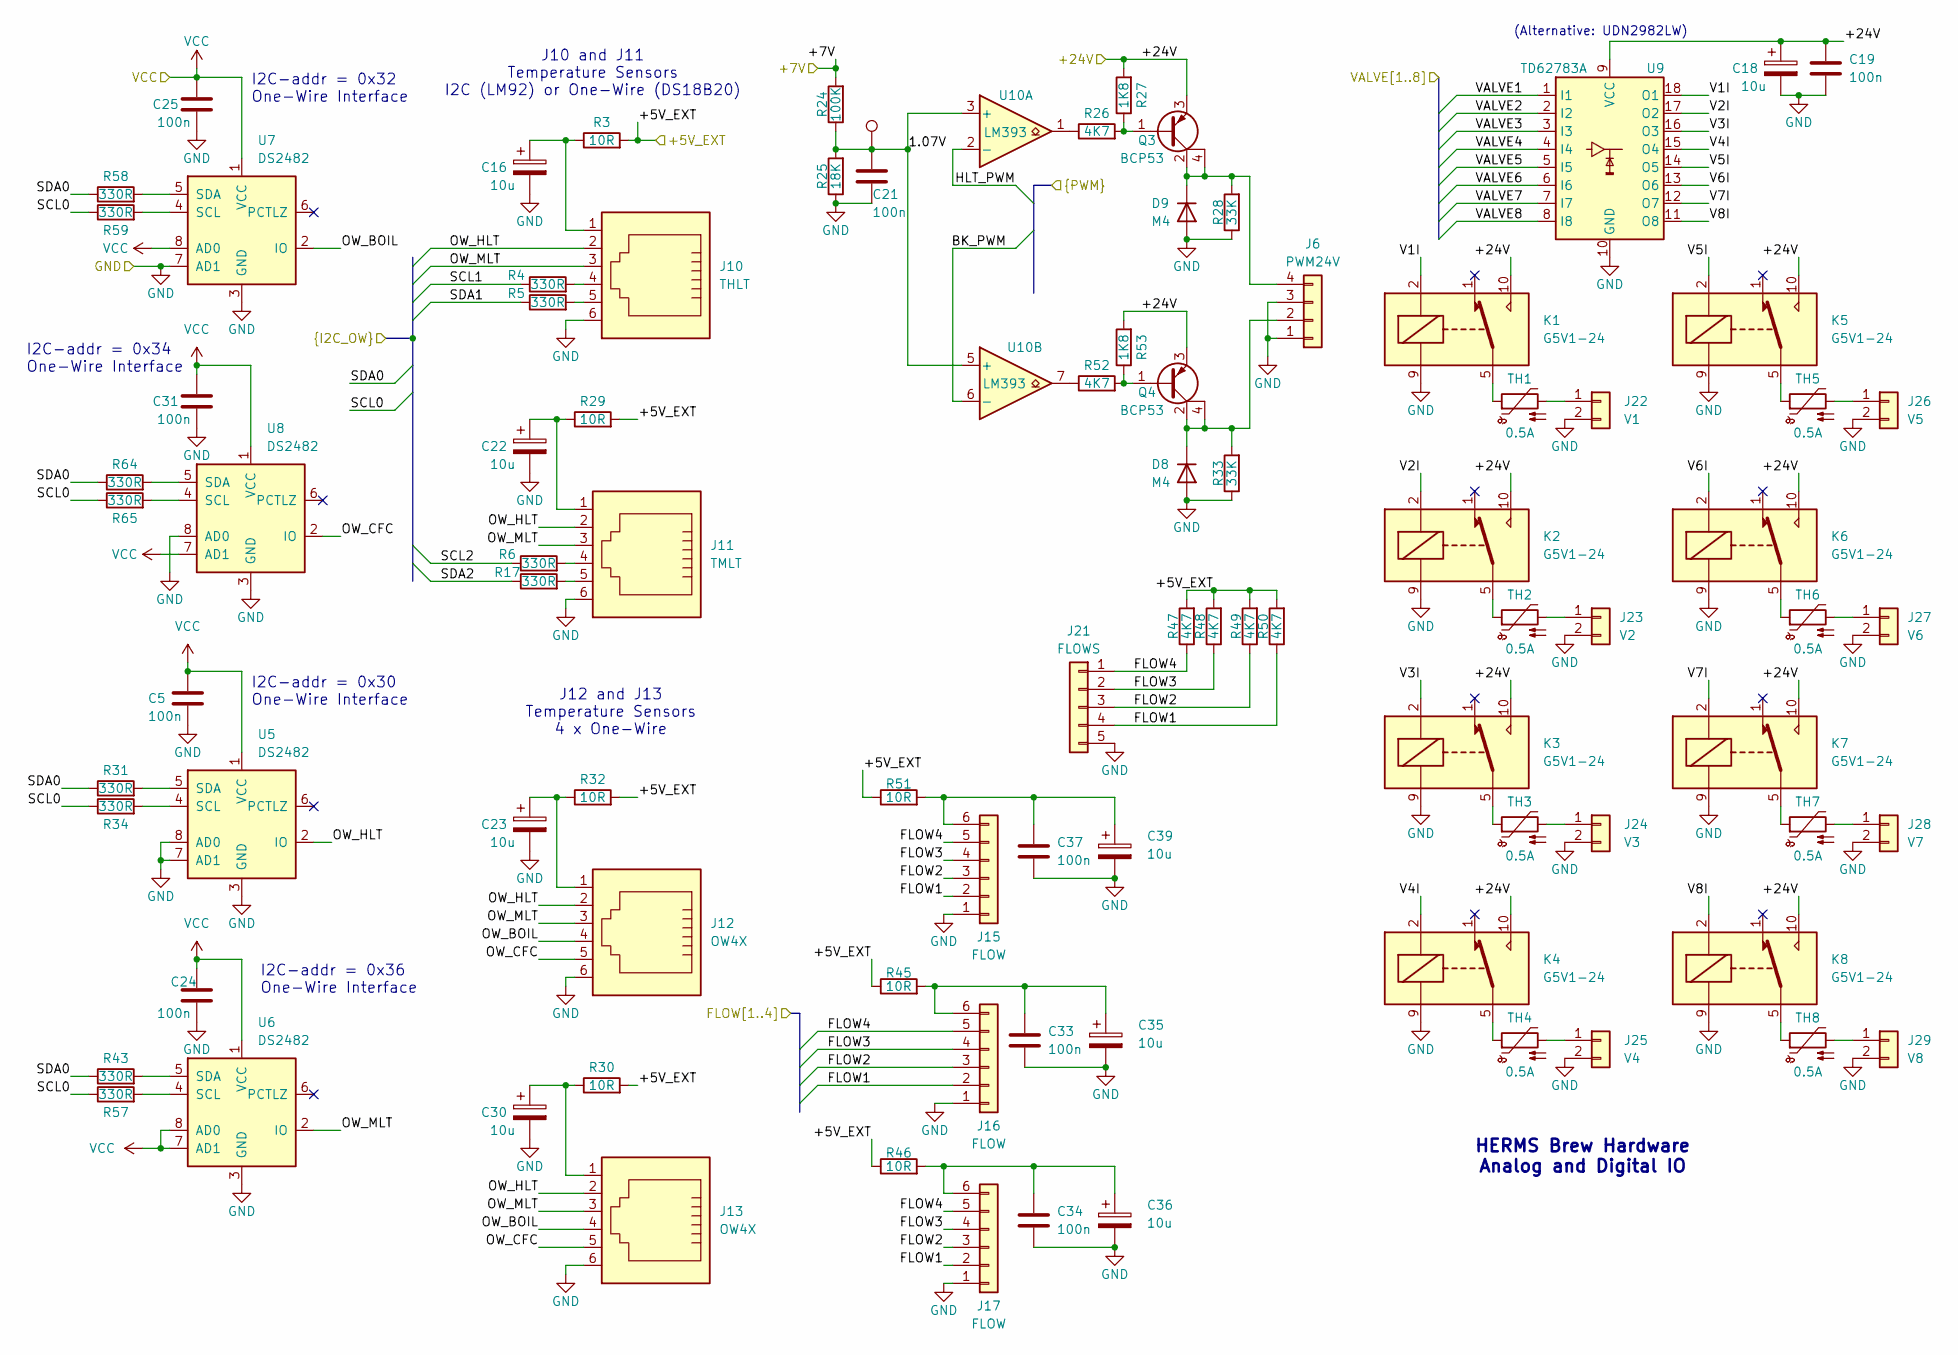
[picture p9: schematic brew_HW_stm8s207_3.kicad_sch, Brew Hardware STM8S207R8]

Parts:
C5, C19, C21, C24, C25, C31, C33, C34, C37: 100n; C_1206_3216Metric
C16, C18, C22, C23, C30, C35, C36, C39: 10u; CP_Radial_D5.0mm_P2.00mm
D8, D9: M4; D_SMA_Handsoldering
J6: PWM24V; PinSocket_1x04_P2.54mm_Vertical
J10: THLT; RJ12_Amphenol_54601-x06_Horizontal
J11: TMLT; RJ12_Amphenol_54601-x06_Horizontal
J12, J13: OW4X; RJ12_Amphenol_54601-x06_Horizontal
J15, J16, J17: FLOW; PS2-MINI-DIN6
J21: FLOWS; PinSocket_1x05_P2.54mm_Vertical
J22: V1; PinSocket_1x02_P2.54mm_Vertical
J23: V2; PinSocket_1x02_P2.54mm_Vertical
J24: V3; PinSocket_1x02_P2.54mm_Vertical
J25: V4; PinSocket_1x02_P2.54mm_Vertical
J26: V5; PinSocket_1x02_P2.54mm_Vertical
J27: V6; PinSocket_1x02_P2.54mm_Vertical
J28: V7; PinSocket_1x02_P2.54mm_Vertical
J29: V8; PinSocket_1x02_P2.54mm_Vertical
K1, K2, K3, K4, K5, K6, K7, K8: G5V1-24; Relay_SPDT_Omron_G5V-1
Q3, Q4: BCP53; SOT-223
R3, R29, R30, R32, R45, R46, R51: 10R; R_1206_3216Metric
R4, R5, R6, R17, R31, R34, R43, R57, R58, R59, R64, R65: 330R; R_1206_3216Metric
R24: 100K; R_1206_3216Metric
R25: 18K; R_1206_3216Metric
R26, R47, R48, R49, R50, R52: 4K7; R_1206_3216Metric
R27, R53: 1K8; R_1206_3216Metric
R28, R33: 33K; R_1206_3216Metric
TH1, TH2, TH3, TH4, TH5, TH6, TH7, TH8: 0.5A; R_Box_L8.4mm_W2.5mm_P5.08mm
TP15: 1V07; TestPoint_Pad_D1.0mm
U5, U6, U7, U8: DS2482; SOIC-8_3.9x4.9mm_P1.27mm
U9: TD62783A; SOIC-18W_7.5x11.6mm_P1.27mm
U10: LM393; DIP-8_W7.62mm

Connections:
/Digital IO and Connectors/1.07V: C21.1, R24.1, R25.2, TP15.1 (1_1), U10.3 (+), U10.5 (+)
/Digital IO and Connectors/+5V_EXT: R3.2, R29.2, R30.2, R32.2, R45.1, R46.1, R47.2, R48.2, R49.2, R50.2, R51.1; also elsewhere on the board
/Digital IO and Connectors/+7V: R24.2; also elsewhere on the board
/Digital IO and Connectors/+24V: C18.1, C19.1, K1.10, K2.10, K3.10, K4.10, K5.10, K6.10, K7.10, K8.10, Q3.3 (E), Q4.3 (E), R27.2, R53.2, U9.9 (VCC); also elsewhere on the board
/Digital IO and Connectors/BK_PWM: U10.6 (-); also elsewhere on the board
/Digital IO and Connectors/FLOW1: J15.2, J16.2, J17.2, J21.4, R50.1; also elsewhere on the board
/Digital IO and Connectors/FLOW2: J15.3, J16.3, J17.3, J21.3, R49.1; also elsewhere on the board
/Digital IO and Connectors/FLOW3: J15.4, J16.4, J17.4, J21.2, R48.1; also elsewhere on the board
/Digital IO and Connectors/FLOW4: J15.5, J16.5, J17.5, J21.1, R47.1; also elsewhere on the board
/Digital IO and Connectors/HLT_PWM: U10.2 (-); also elsewhere on the board
/Digital IO and Connectors/OW_BOIL: J12.4, J13.4, U7.2 (IO)
/Digital IO and Connectors/OW_CFC: J12.5, J13.5, U8.2 (IO)
/Digital IO and Connectors/OW_HLT: J10.2, J11.2, J12.2, J13.2, U5.2 (IO); also elsewhere on the board
/Digital IO and Connectors/OW_MLT: J10.3, J11.3, J12.3, J13.3, U6.2 (IO); also elsewhere on the board
/Digital IO and Connectors/SCL0: R34.1, R57.1, R59.1, R65.1; also elsewhere on the board
/Digital IO and Connectors/SCL1: R4.1; also elsewhere on the board
/Digital IO and Connectors/SCL2: R6.1; also elsewhere on the board
/Digital IO and Connectors/SDA0: R31.1, R43.1, R58.1, R64.1; also elsewhere on the board
/Digital IO and Connectors/SDA1: R5.1; also elsewhere on the board
/Digital IO and Connectors/SDA2: R17.1; also elsewhere on the board
/Digital IO and Connectors/V1I: K1.2, U9.18 (O1)
/Digital IO and Connectors/V2I: K2.2, U9.17 (O2)
/Digital IO and Connectors/V3I: K3.2, U9.16 (O3)
/Digital IO and Connectors/V4I: K4.2, U9.15 (O4)
/Digital IO and Connectors/V5I: K5.2, U9.14 (O5)
/Digital IO and Connectors/V6I: K6.2, U9.13 (O6)
/Digital IO and Connectors/V7I: K7.2, U9.12 (O7)
/Digital IO and Connectors/V8I: K8.2, U9.11 (O8)
/Digital IO and Connectors/VALVE1: U9.1 (I1); also elsewhere on the board
/Digital IO and Connectors/VALVE2: U9.2 (I2); also elsewhere on the board
/Digital IO and Connectors/VALVE3: U9.3 (I3); also elsewhere on the board
/Digital IO and Connectors/VALVE4: U9.4 (I4); also elsewhere on the board
/Digital IO and Connectors/VALVE5: U9.5 (I5); also elsewhere on the board
/Digital IO and Connectors/VALVE6: U9.6 (I6); also elsewhere on the board
/Digital IO and Connectors/VALVE7: U9.7 (I7); also elsewhere on the board
/Digital IO and Connectors/VALVE8: U9.8 (I8); also elsewhere on the board
GND: C5.2, C16.2, C18.2, C19.2, C21.2, C22.2, C23.2, C24.2, C25.2, C30.2, C31.2, C33.2, C34.2, C35.2, C36.2, C37.2, C39.2, D8.2 (A), D9.2 (A), J6.1, J6.3, J10.6, J11.6, J12.6, J13.6, J15.1, J16.1, J17.1, J21.5, J22.2, J23.2, J24.2, J25.2, J26.2, J27.2, J28.2, J29.2, K1.9, K2.9, K3.9, K4.9, K5.9, K6.9, K7.9, K8.9, R25.1, R28.1, R33.1, U5.3 (GND), U5.7 (AD1), U5.8 (AD0), U6.3 (GND), U7.3 (GND), U7.7 (AD1), U8.3 (GND), U8.8 (AD0), U9.10 (GND); also elsewhere on the board
unnamed: C16.1, J10.1, R3.1
unnamed: C22.1, J11.1, R29.1
unnamed: C23.1, J12.1, R32.1
unnamed: C30.1, J13.1, R30.1
unnamed: D8.1 (K), J6.2, Q4.2 (C), Q4.4 (C), R33.2
unnamed: D9.1 (K), J6.4, Q3.2 (C), Q3.4 (C), R28.2
unnamed: J10.4, R4.2
unnamed: J10.5, R5.2
unnamed: J11.4, R6.2
unnamed: J11.5, R17.2
unnamed: C37.1, C39.1, J15.6, R51.2
unnamed: C33.1, C35.1, J16.6, R45.2
unnamed: C34.1, C36.1, J17.6, R46.2
unnamed: J22.1, TH1.2
unnamed: J23.1, TH2.2
unnamed: J24.1, TH3.2
unnamed: J25.1, TH4.2
unnamed: J26.1, TH5.2
unnamed: J27.1, TH6.2
unnamed: J28.1, TH7.2
unnamed: J29.1, TH8.2
unnamed: K1.5, K1.6, TH1.1
unnamed: K2.5, K2.6, TH2.1
unnamed: K3.5, K3.6, TH3.1
unnamed: K4.5, K4.6, TH4.1
unnamed: K5.5, K5.6, TH5.1
unnamed: K6.5, K6.6, TH6.1
unnamed: K7.5, K7.6, TH7.1
unnamed: K8.5, K8.6, TH8.1
unnamed: Q3.1 (B), R26.2, R27.1
unnamed: Q4.1 (B), R52.2, R53.1
unnamed: R26.1, U10.1
unnamed: R52.1, U10.7
unnamed: R34.2, U5.4 (SCL)
unnamed: R31.2, U5.5 (SDA)
unnamed: R57.2, U6.4 (SCL)
unnamed: R43.2, U6.5 (SDA)
unnamed: R59.2, U7.4 (SCL)
unnamed: R58.2, U7.5 (SDA)
unnamed: R65.2, U8.4 (SCL)
unnamed: R64.2, U8.5 (SDA)
VCC: C5.1, C24.1, C25.1, C31.1, U5.1 (VCC), U6.1 (VCC), U6.7 (AD1), U6.8 (AD0), U7.1 (VCC), U7.8 (AD0), U8.1 (VCC), U8.7 (AD1); also elsewhere on the board

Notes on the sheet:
I2C-addr = 0x34 One-Wire Interface
(Alternative: UDN2982LW)
J12 and J13 Temperature Sensors 4 x One-Wire
I2C-addr = 0x30 One-Wire Interface
HERMS Brew Hardware Analog and Digital IO
I2C-addr = 0x32 One-Wire Interface
I2C-addr = 0x36 One-Wire Interface
J10 and J11 Temperature Sensors I2C (LM92) or One-Wire (DS18B20)

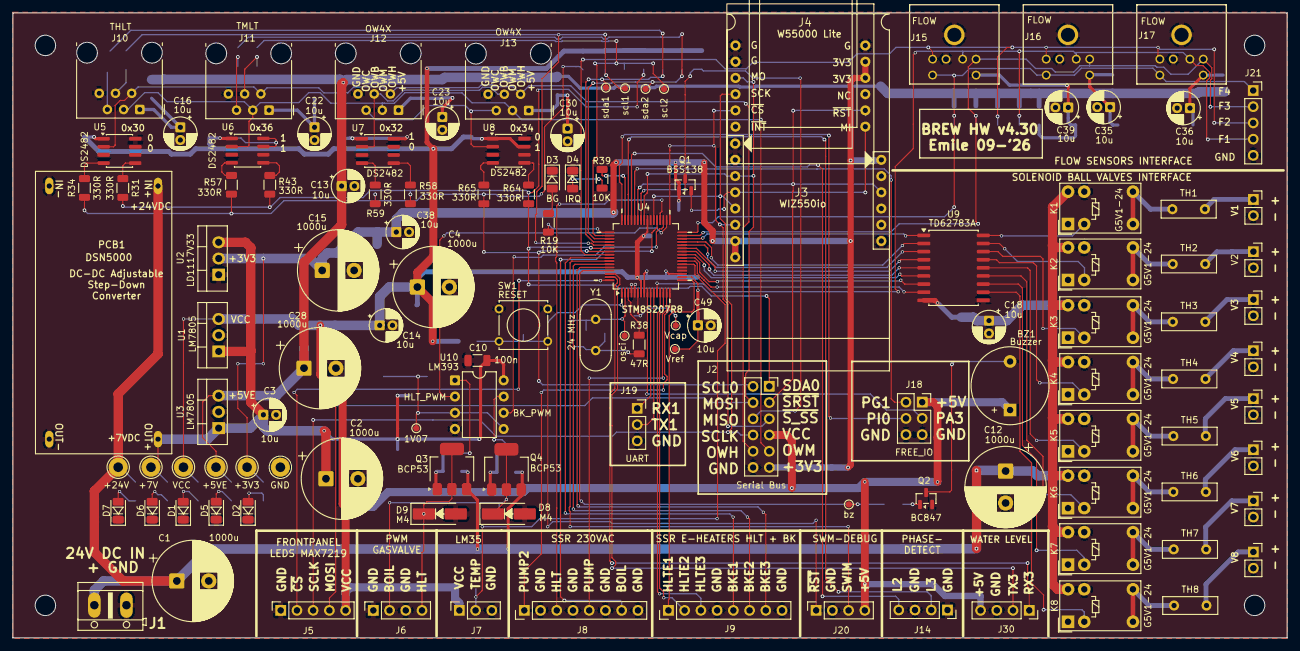
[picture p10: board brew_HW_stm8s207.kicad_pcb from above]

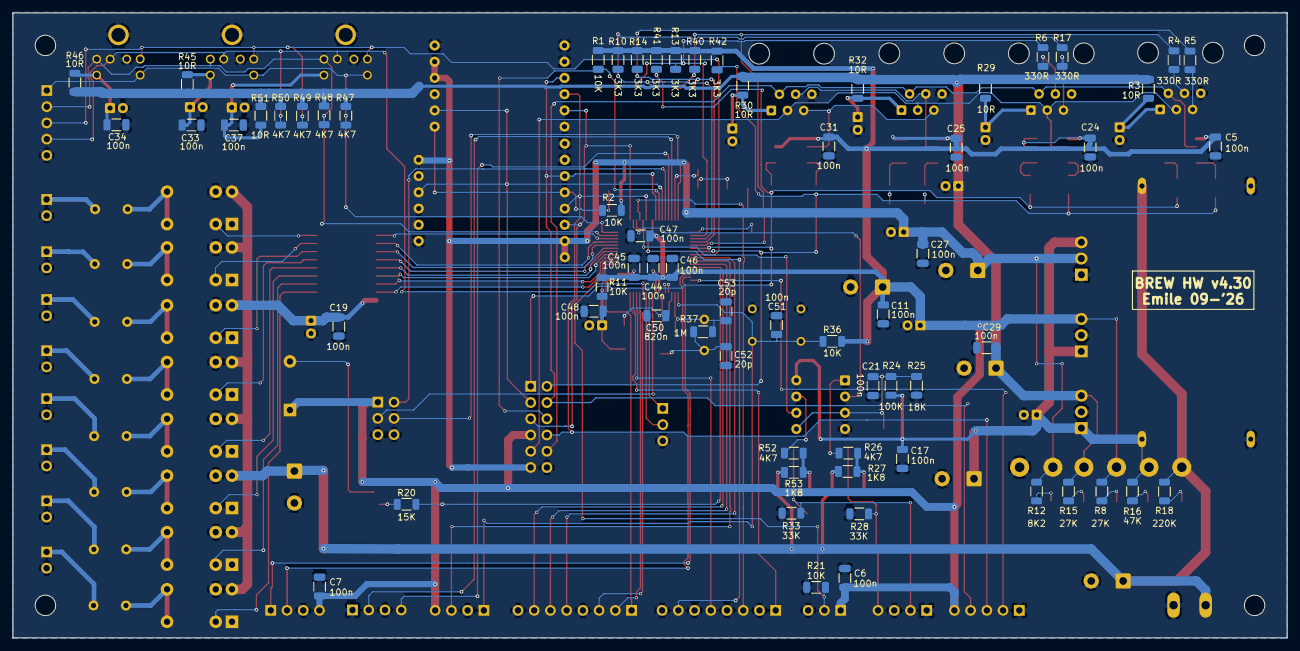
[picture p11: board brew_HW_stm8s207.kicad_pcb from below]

Board: 2 copper layers, 199.4 x 97.8 mm, 188 parts (65 on the bottom side), 126 nets.

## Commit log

2026-08-16 1st github commit of Kicad project Brew_HW_STM8S207
    This is an exact copy of V4.21, made with Kicad 9.0.
    [brew_HW_stm8s207.kicad_pcb, brew_HW_stm8s207.kicad_sch, brew_HW_stm8s207_1.kicad_sch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]
2026-08-16 Readme and .gitignore added
    [brew_HW_stm8s207.kicad_pcb]
2026-08-16 Upgrade to Kicad 10
    [brew_HW_stm8s207.kicad_pcb, brew_HW_stm8s207.kicad_sch, brew_HW_stm8s207_1.kicad_sch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]
2026-09-27 Brew HW R4.30 kicad files
    [brew_HW_stm8s207.kicad_pcb, brew_HW_stm8s207.kicad_sch, brew_HW_stm8s207_1.kicad_sch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]
